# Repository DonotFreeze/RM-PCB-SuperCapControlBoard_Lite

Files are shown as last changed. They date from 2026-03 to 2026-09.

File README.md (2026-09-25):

# 超级电容控制板 Lite

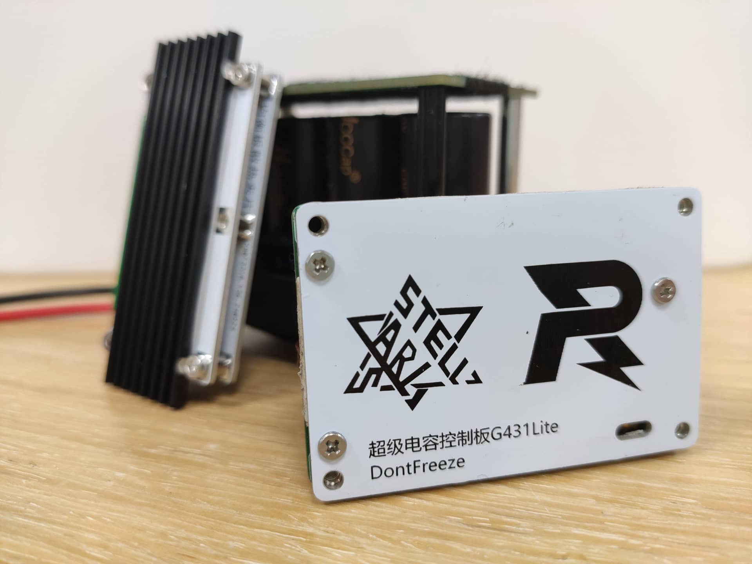
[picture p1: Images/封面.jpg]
超级电容控制板 Lite 封面


> 桂林理工大学 · 群星战队 · RoboMaster 2024 赛季开源工程

基于 **STM32G431CB** 的单半桥双向同步 Buck-Boost 超级电容控制板，用于 RoboMaster 机甲大师赛 2024 赛季高校联盟赛、超级对抗赛以及 2025 赛季高校联盟赛。Lite 版本在**保留上一代半桥功率拓扑**的前提下，对外围芯片重新选型，尽量精简外围电路，希望以较小的成本和体积实现较高的性能，并补充了半桥关键测试点与便于调试的板载资源。

> **完整的硬件设计说明** → [RM2024 超级电容控制板 Lite「硬件篇」 · DonotFreeze 的知识库](https://donotfreeze.github.io/robomaster/supercap-controller-lite-hardware/)

## 主要特性

- **单电感同步半桥**：PMOS 防倒灌 + 半桥 Buck/Boost，与半桥 NMOS 的体二极管方向相反，两者同时截止即可完全断开电容组与母线。
- **100 kHz 开关频率**：STM32G4 的 PWM 抖动模式可将分辨率提升至最高 20 位，100 kHz 下约 27200 个计数值可用（未开启时仅 1700），并使用内部 2.5 V 基准作为 ADC 参考，减小 LDO 精度对采样的影响。
- **完整的采样链路**：母线电流单向高边采样（INA139）、电容组电流双向采样（INA181A2 + 1.65 V 偏置）、母线/电容组电压电阻分压，均经 RC 10 kHz 低通滤波后送入 ADC。
- **温度监控**：半桥附近板载 NTC，电容组温度经 MX1.25 接口外接 NTC，为软件过温保护提供依据。
- **调试友好**：半桥关键测试点、复位/复用按键、拨码开关、两路状态指示灯、SWD 下载口。
- **小体积**：约 60 × 40 mm，配合电容组与裁判系统电源管理模块可塞入装甲板支架之间的位置。

## 硬件规格

| 项目 | 参数 |
| --- | --- |
| 主控 | STM32G431CBT6 |
| 拓扑 | 同步 Buck-Boost 半桥（降压充电 / 升压放电） |
| 开关频率 | 100 kHz（PWM 抖动模式） |
| 半桥 MOS | IRFH7440TRPBF × 2 |
| 防倒灌 PMOS | AGM60P100A |
| 栅极驱动 | EG2181 |
| 电感 | 106-125 磁环 11 匝 ≈ 22 µH（16 A 偏置下约 10.9 µH） |
| 母线电流采样 | 2 mΩ + INA139（单向，量程约 12.5 A） |
| 电容电流采样 | 1 mΩ + INA181A2（双向，+17 A / −33 A） |
| 电压采样 | 电阻分压 + LMV321 跟随器 |
| 温度采样 | 半桥 NTC + 外接电容组 NTC |
| 通信 | CAN |
| 辅助电源 | JW5026 × 2（24 V → 10 V / 4 V）+ RT9193（3.3 V） |
| 保护 | 母线 TVS、电容端口 TVS `SMCJ22A`、辅助电源输入自恢复保险丝 |
| 尺寸 | 约 60 × 40 mm × 1.6 mm |

## 工程结构

```text
├─ SuperCapPowerBoard_Lite.kicad_pro   # KiCad 8.0 工程文件
├─ SuperCapPowerBoard_Lite.kicad_sch   # 主控原理图
├─ SuperCapPowerBoard_Lite.kicad_pcb   # PCB 布局与走线
├─ POWER.kicad_sch                     # 功率级原理图
├─ bom/
│  └─ BOM_LITE_2610.html               # 交互式 BOM（点击可定位元件）
├─ GERBER/
│  └─ GERBER_LITE_2610.zip             # Gerber 与钻孔文件
├─ Images/                             # 文档配图
└─ CHANGELOG.md                        # 版本更新日志
```

## 固件代码

本仓库为**纯硬件工程**，不包含固件源码。固件由以下两个独立仓库提供，与本硬件配套使用：

| 仓库 | 说明 |
| --- | --- |
| [**RM-CODE-SuperCapControlBoard_Lite**](https://github.com/DonotFreeze/RM-CODE-SuperCapControlBoard_Lite) | RM2024 赛季超级电容控制板 Lite 的 **CubeMX 代码初始化工程**，提供 STM32 底层外设的 CubeMX 配置 |
| [**RM-SuperCapCtrlLib**](https://github.com/DonotFreeze/RM-SuperCapCtrlLib) | 参加 RoboMaster 机甲大师赛期间开发的 **C 语言库**，可同时用于超级电容控制板 **Lite 和 Plus**，负责充放电环路控制与对外接口 |

## 物料与打样

- BOM 见 `bom/BOM_LITE_2610.html`，Gerber 生产文件见 `GERBER/GERBER_LITE_2610.zip`，可直接送厂打样。
- **磁环电感需自行采购**：`106-125` 磁环（四线 1.0 mm 并绕 11 匝，初始感量约 22 µH）。
- 电容类元件耐压建议 ≥ 35 V；母线侧元件按电池满电 26 V 以上留足冗余。
- 成本参考 84 RMB/套（2024 年 10 月）。

## 参考资料

设计过程中参考的应用笔记与手册如下，完整的设计思路与参数推导见文首的「硬件篇」：

- 《RM0440 - STM32G4 系列参考手册》（PWM 抖动模式、ADC 相关章节）
- 《AN2834 - 如何在 STM32 微控制器中获得最佳 ADC 精度》
- 《AN5690 - 如何在 STM32 MCU 和 MPU 上使用 VREFBUF 外设》
- 《LAT1076 - STM32G4 Advanced Timer Break 功能详解》
- 《LAT1444 - ADC 采样中的阻抗匹配计算方法》
- 《MOSFET 驱动器与 MOSFET 的匹配设计》
- 《低压非隔离 DCDC 开关稳压器设计》
- 《精密低噪声电源设计 - 理论篇》
- 《热回路究竟是什么？》
- 《如何通过最小化热回路 PCB ESR 和 ESL 来优化开关电源布局》
- 《改进低值分流电阻的焊盘布局，优化高电流检测精度》

## 许可证

本作品采用 [CC-BY-4.0](LICENSE) 许可协议进行授权，欢迎转载，但请务必保留作者署名。

## 相关链接

- [RM2024 超级电容控制板 Lite「硬件篇」](https://donotfreeze.github.io/robomaster/supercap-controller-lite-hardware/)（本工程的设计说明）
- [固件代码 · RM-CODE-SuperCapControlBoard_Lite](https://github.com/DonotFreeze/RM-CODE-SuperCapControlBoard_Lite)（CubeMX 代码初始化工程）
- [固件代码 · RM-SuperCapCtrlLib](https://github.com/DonotFreeze/RM-SuperCapCtrlLib)（Lite / Plus 通用的 C 语言库）
- [RM2025 超级电容控制板 Plus「硬件篇」](https://donotfreeze.github.io/robomaster/supercap-controller-plus-hardware/)
- [RM2024 超级电容模组 Lite「使用手册」](https://donotfreeze.github.io/robomaster/supercap-module-lite-user-manual/)
- [RM24-25 超级电容控制板 Lite & Plus「CubeMX 篇」](https://donotfreeze.github.io/robomaster/supercap-controller-cubemx/)
- [RM24-25 超级电容控制板 Lite & Plus「软件篇」](https://donotfreeze.github.io/robomaster/supercap-controller-software/)
- [RM24-25 超级电容模组 Lite & Plus「维护手册」](https://donotfreeze.github.io/robomaster/supercap-module-maintenance-manual/)
- [RM24-25 超级电容模组 Lite & Plus「答疑篇」](https://donotfreeze.github.io/robomaster/supercap-module-faq/)
- [DonotFreeze 的知识库](https://donotfreeze.github.io/)

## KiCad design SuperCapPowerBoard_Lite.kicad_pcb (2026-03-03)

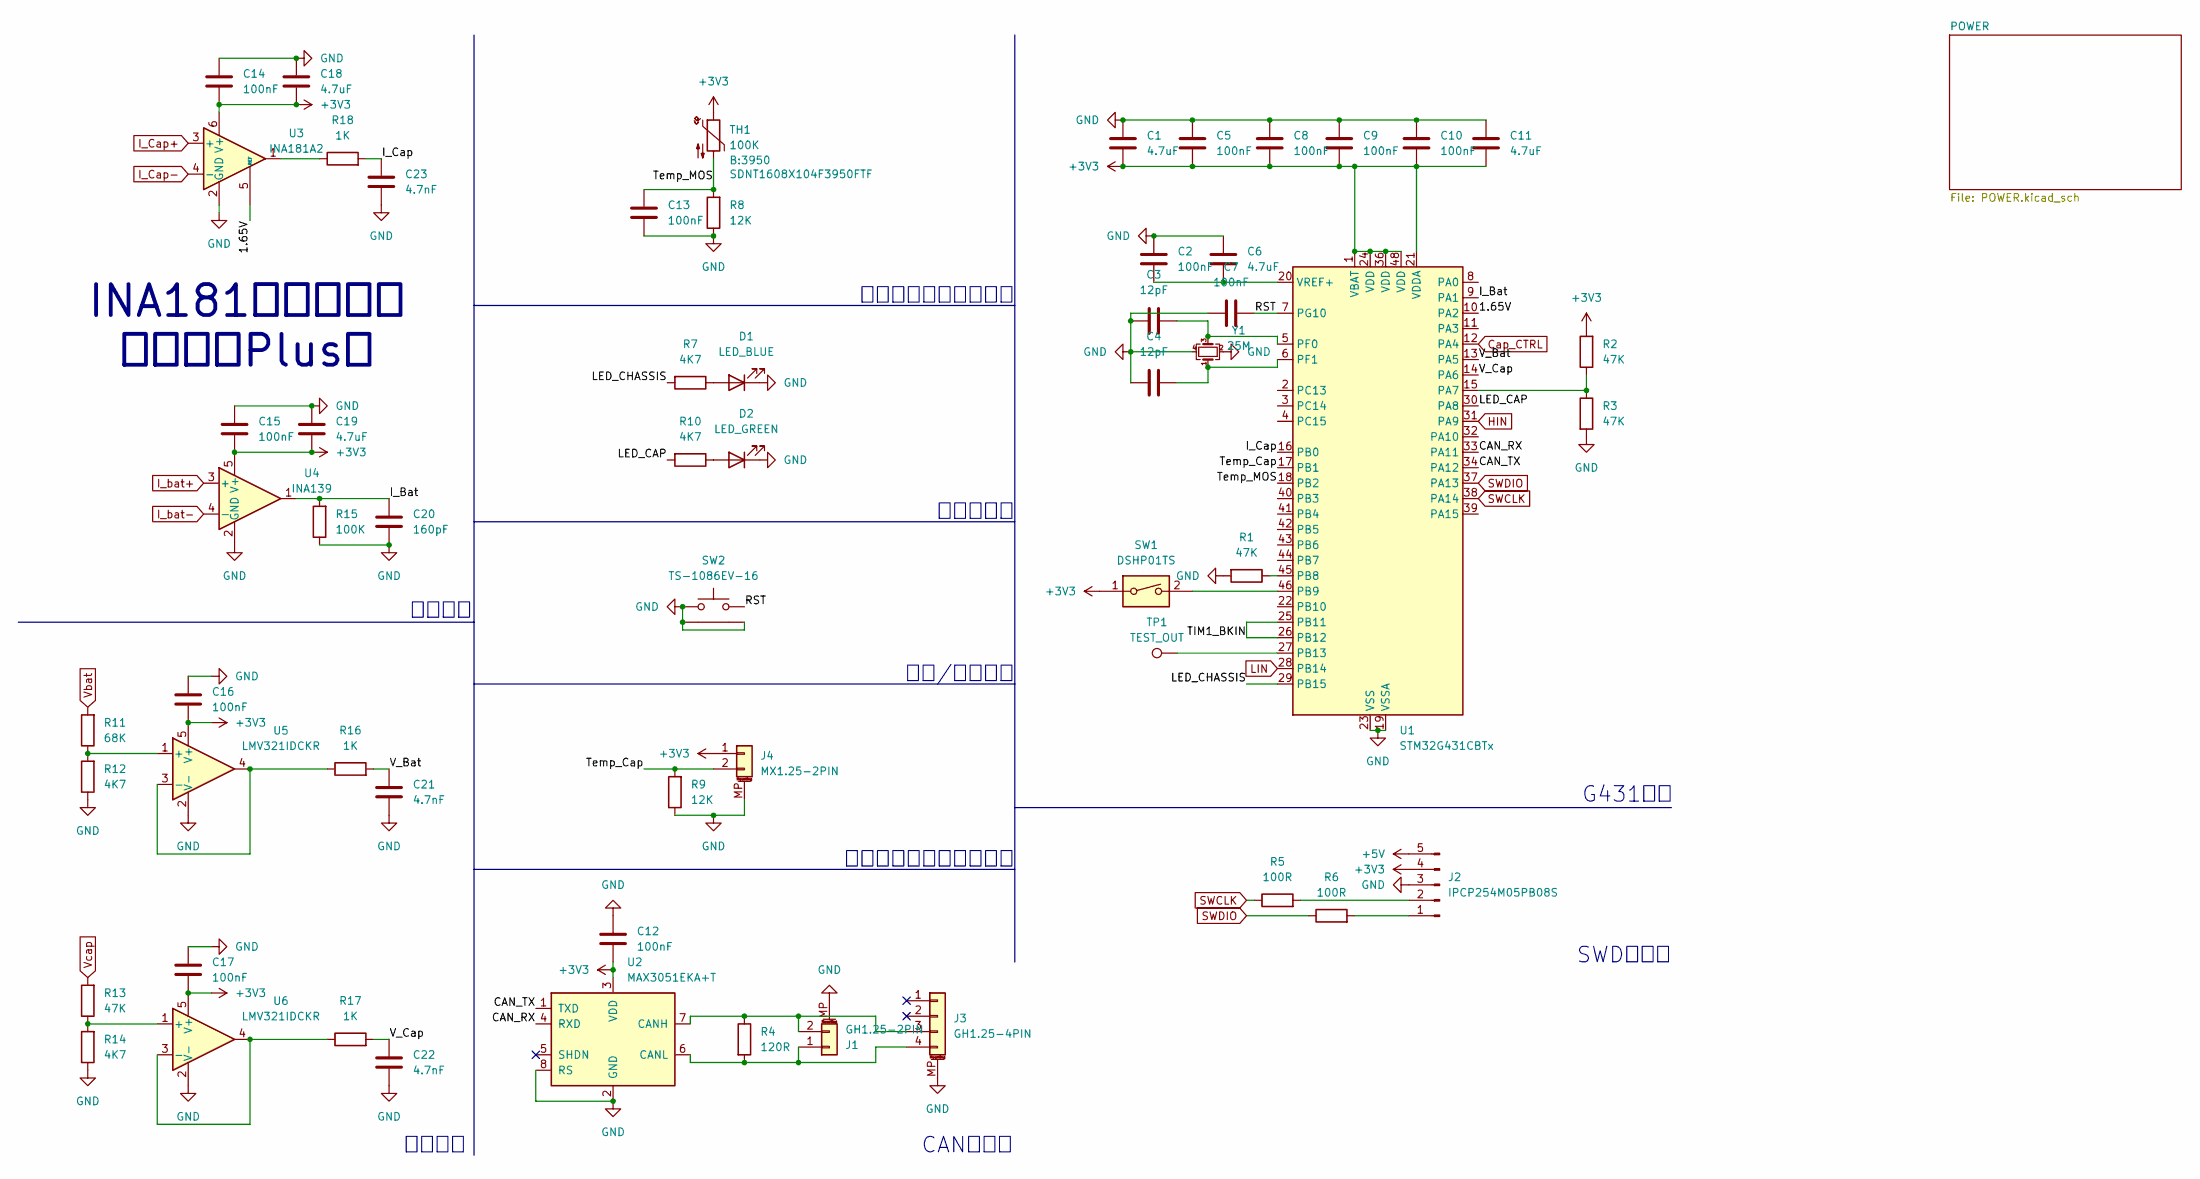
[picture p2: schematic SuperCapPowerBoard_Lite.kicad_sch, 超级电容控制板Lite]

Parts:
C1, C6, C11, C18, C19: 4.7uF; C_0603_1608Metric
C2, C5, C7, C8, C9, C10, C12, C13, C14, C15, C16, C17: 100nF; C_0603_1608Metric
C3, C4: 12pF; C_0603_1608Metric
C20: 160pF; C_0603_1608Metric
C21, C22, C23: 4.7nF; C_0603_1608Metric
D1: LED_BLUE; LED_0805_2012Metric
D2: LED_GREEN; LED_0805_2012Metric
J1: GH1.25-2PIN; JST_GH_BM02B-GHS-TBT_1x02-1MP_P1.25mm_Vertical
J2: IPCP254M05PB08S; PinHeader_1x05_P2.54mm_Vertical_SMD_Pin1Left
J3: GH1.25-4PIN; JST_GH_BM04B-GHS-TBT_1x04-1MP_P1.25mm_Vertical
J4: MX1.25-2PIN; Molex_PicoBlade_53398-0271_1x02-1MP_P1.25mm_Vertical
R1, R2, R3, R13: 47K; R_0603_1608Metric
R4: 120R; R_0603_1608Metric
R5, R6: 100R; R_0603_1608Metric
R7, R10, R12, R14: 4K7; R_0603_1608Metric
R8, R9: 12K; R_0603_1608Metric
R11: 68K; R_0603_1608Metric
R15: 100K; R_0603_1608Metric
R16, R17, R18: 1K; R_0603_1608Metric
SW1: DSHP01TS; SW_DIP_SPSTx01_Slide_Copal_CHS-01B_W7.62mm_P1.27mm
SW2: TS-1086EV-16; SW_Push_1P1T-MP_NO_TS-1086EV-AR03526
TH1: 100K; R_0603_1608Metric
TP1: TEST_OUT; TestPoint_Pad_D1.5mm
U1: STM32G431CBTx; LQFP-48_7x7mm_P0.5mm
U2: MAX3051EKA+T; SOT-23-8
U3: INA181A2; SOT-23-6
U4: INA139; SOT-23-5
U5, U6: LMV321IDCKR; SOT-353_SC-70-5
Y1: 25M; Crystal_SMD_2016-4Pin_2.0x1.6mm

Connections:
+3V3: C1.2, C5.2, C8.2, C9.2, C10.2, C11.2, C12.2, C14.1, C15.1, C16.1, C17.1, C18.1, C19.1, J2.4, J4.1, R2.2, SW1.1, TH1.1, U1.1 (VBAT), U1.21 (VDDA), U1.24 (VDD), U1.36 (VDD), U1.48 (VDD), U2.3 (VDD), U3.6 (V+), U4.5 (V+), U5.5 (V+), U6.5 (V+); also elsewhere on the board
+5V: J2.5; also elsewhere on the board
/1.65V: U1.10 (PA2), U3.5 (REF)
/CAN_RX: U1.33 (PA11), U2.4 (RXD)
/CAN_TX: U1.34 (PA12), U2.1 (TXD)
/I_Bat: C20.2, R15.2, U1.9 (PA1), U4.1
/I_Cap: C23.2, R18.2, U1.16 (PB0)
/LED_CAP: R10.2, U1.30 (PA8)
/LED_CHASSIS: R7.2, U1.29 (PB15)
/RST: C7.2, SW2.2, U1.7 (PG10)
/TIM1_BKIN: U1.25 (PB11), U1.26 (PB12)
/Temp_Cap: J4.2, R9.2, U1.17 (PB1)
/Temp_MOS: C13.1, R8.2, TH1.2, U1.18 (PB2)
/V_Bat: C21.2, R16.2, U1.13 (PA5)
/V_Cap: C22.2, R17.2, U1.14 (PA6)
Cap_CTRL: U1.12 (PA4); also elsewhere on the board
GND: C1.1, C2.1, C3.2, C4.2, C5.1, C6.1, C7.1, C8.1, C9.1, C10.1, C11.1, C12.1, C13.2, C14.2, C15.2, C16.2, C17.2, C18.2, C19.2, C20.1, C21.1, C22.1, C23.1, D1.1 (K), D2.1 (K), J1.MP (MountPin), J2.3, J3.MP (MountPin), J4.MP (MountPin), R1.2, R3.2, R8.1, R9.1, R12.1, R14.1, R15.1, SW2.1, SW2.MP, U1.19 (VSSA), U1.23 (VSS), U1.35 (VSS), U1.47 (VSS), U2.2 (GND), U2.8 (RS), U3.2 (GND), U4.2 (GND), U5.2 (V-), U6.2 (V-), Y1.2, Y1.4; also elsewhere on the board
HIN: U1.31 (PA9); also elsewhere on the board
I_Cap+: U3.3 (+); also elsewhere on the board
I_Cap-: U3.4 (-); also elsewhere on the board
I_bat+: U4.3 (+); also elsewhere on the board
I_bat-: U4.4 (-); also elsewhere on the board
LIN: U1.28 (PB14); also elsewhere on the board
unnamed: D1.2 (A), R7.1
unnamed: D2.2 (A), R10.1
unnamed: J1.1, J3.4, R4.2, U2.6 (CANL)
unnamed: J1.2, J3.3, R4.1, U2.7 (CANH)
unnamed: J2.1, R6.2
unnamed: J2.2, R5.2
unnamed: R18.1, U3.1
unnamed: R2.1, R3.1, U1.15 (PA7)
unnamed: R1.1, U1.45 (PB8)
unnamed: SW1.2, U1.46 (PB9)
unnamed: TP1.1, U1.27 (PB13)
unnamed: C3.1, U1.5 (PF0), Y1.3
unnamed: C4.1, U1.6 (PF1), Y1.1
unnamed: C2.2, C6.2, U1.20 (VREF+)
unnamed: R11.1, R12.2, U5.1 (+)
unnamed: R16.1, U5.3 (-), U5.4
unnamed: R13.1, R14.2, U6.1 (+)
unnamed: R17.1, U6.3 (-), U6.4
SWCLK: R5.1, U1.38 (PA14)
SWDIO: R6.1, U1.37 (PA13)
Vbat: R11.2; also elsewhere on the board
Vcap: R13.2; also elsewhere on the board

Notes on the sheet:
CAN收发器
INA181有烧毁风险 建议使用Plus版
半桥温度检测热敏电阻
电压检测
G431主控
SWD下载口
电流检测
复位/复用按键
状态指示灯
电容组温度检测热敏电阻

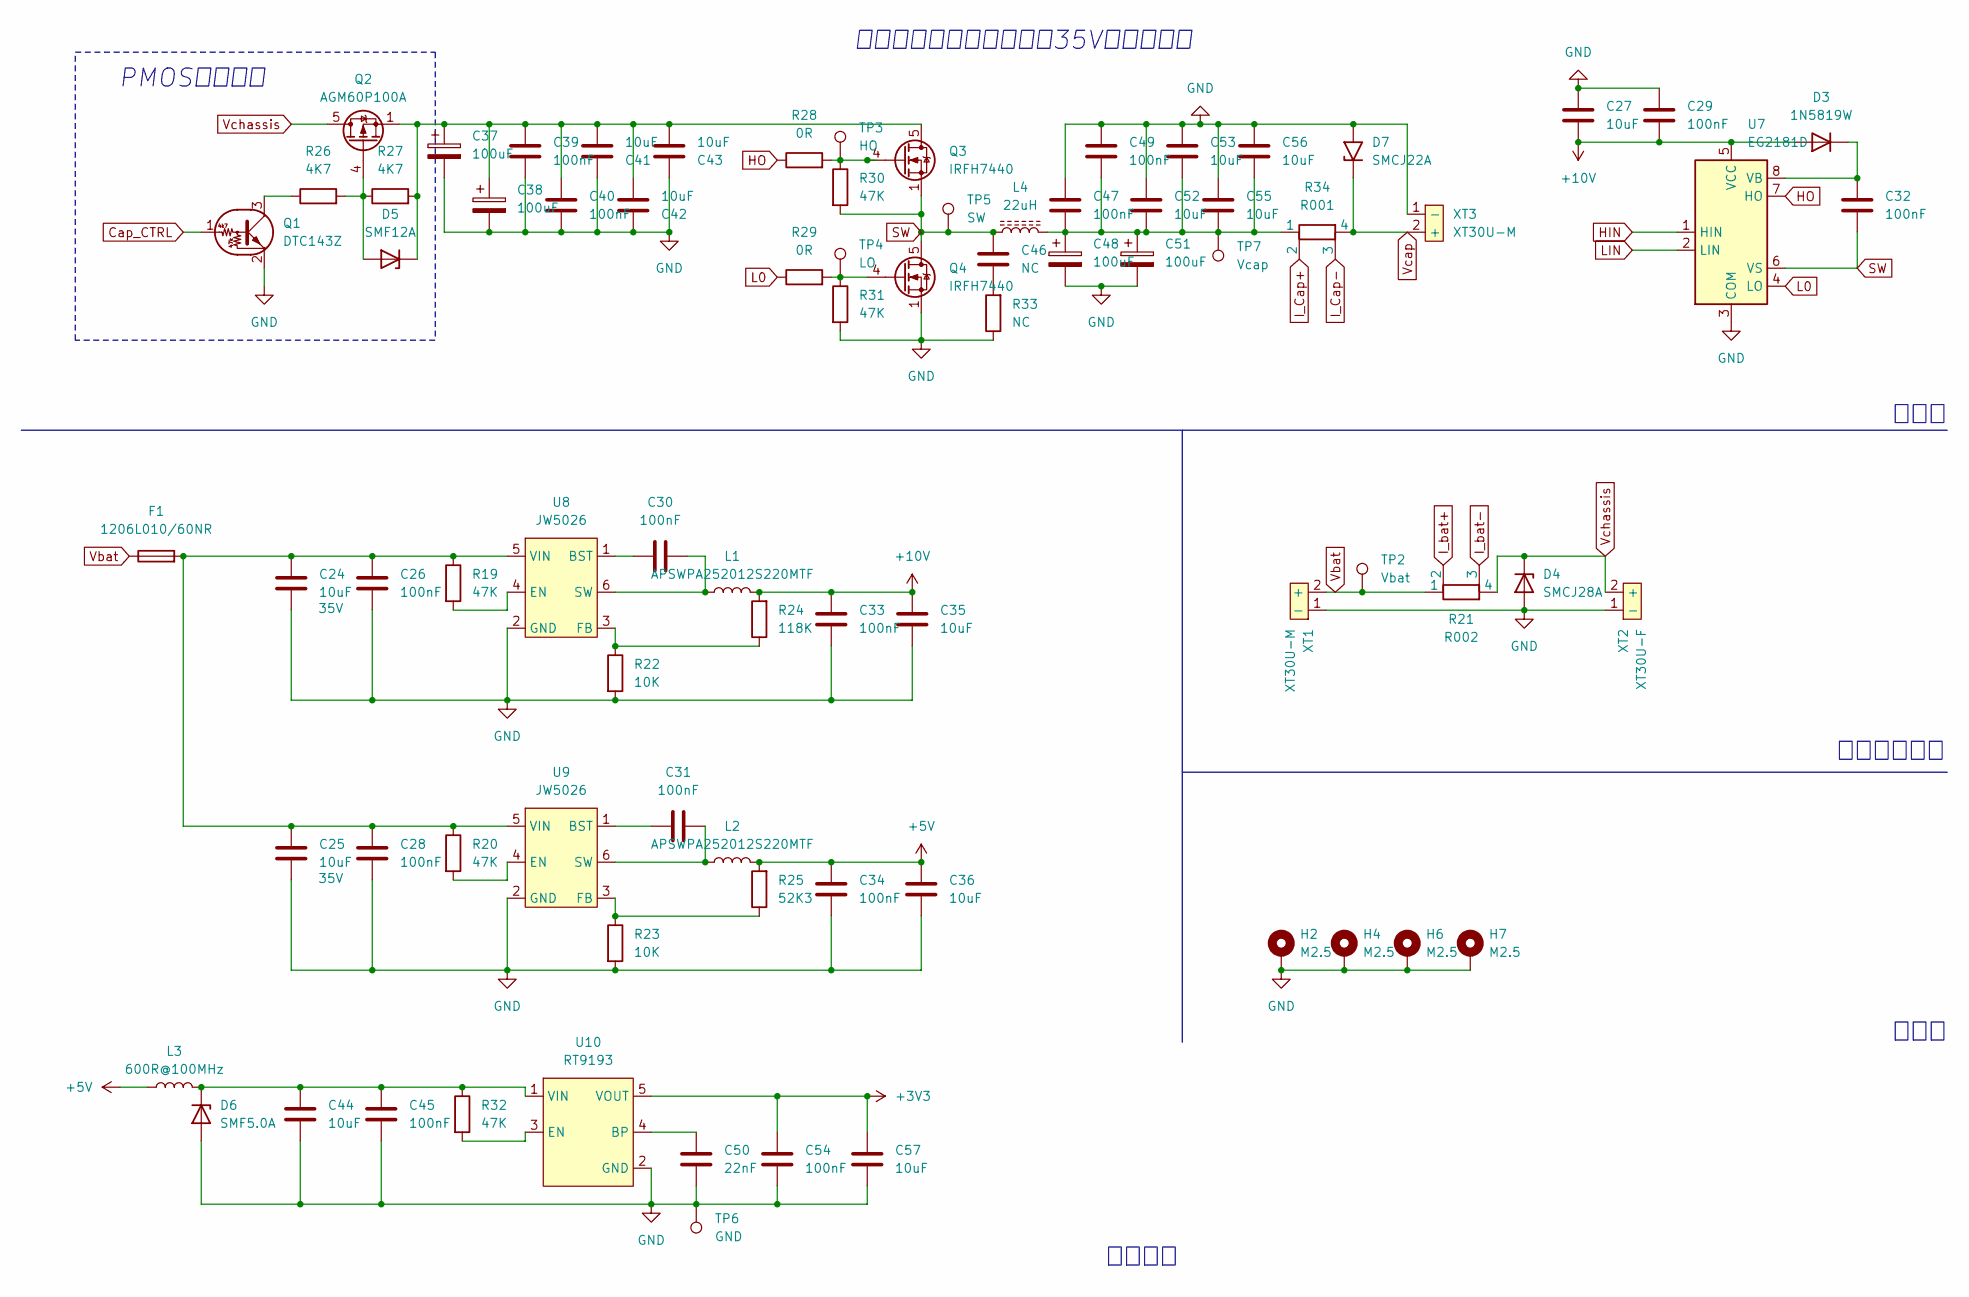
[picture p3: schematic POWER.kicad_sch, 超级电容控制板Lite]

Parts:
C24, C25, C41, C42, C43, C52, C53, C55, C56: 10uF; C_1206_3216Metric
C26, C28, C29, C30, C31, C32, C33, C34, C39, C40, C45, C47, C49, C54: 100nF; C_0603_1608Metric
C27, C35, C36, C44, C57: 10uF; C_0603_1608Metric
C37, C38, C48, C51: 100uF; CP_Radial_D8.0mm_P3.50mm
C46: NC; C_0603_1608Metric
C50: 22nF; C_0603_1608Metric
D3: 1N5819W; D_SOD-123F
D4: SMCJ28A; D_SMC
D5: SMF12A; D_SOD-123F
D6: SMF5.0A; D_SOD-123F
D7: SMCJ22A; D_SMC
F1: 1206L010/60NR; Fuse_1206_3216Metric
H2, H4, H6, H7: M2.5; MountingHole_3.1mm_M2.5
L1, L2: APSWPA252012S220MTF; L_Sunlord_SWPA252012S
L3: 600R@100MHz; L_0805_2012Metric
L4: 22uH; L_106125
Q1: DTC143Z; SOT-23
Q2: AGM60P100A; AO_DFN-8-1EP_5.55x5.2mm_P1.27mm_EP4.12x4.6mm
Q3, Q4: IRFH7440; TDSON-8-1
R19, R20, R30, R31, R32: 47K; R_0603_1608Metric
R21: R002; R_Shunt_2512_6332Metric
R22, R23: 10K; R_0603_1608Metric
R24: 118K; R_0603_1608Metric
R25: 52K3; R_0603_1608Metric
R26, R27: 4K7; R_0603_1608Metric
R28, R29: 0R; R_0603_1608Metric
R33: NC; R_0603_1608Metric
R34: R001; R_Shunt_2512_6332Metric
TP2: Vbat; TestPoint_Pad_D1.5mm
TP3: HO; TestPoint_Pad_D1.5mm
TP4: LO; TestPoint_Pad_D1.5mm
TP5: SW; TestPoint_Pad_D1.5mm
TP6: GND; TestPoint_Pad_D1.5mm
TP7: Vcap; TestPoint_Pad_D1.5mm
U7: EG2181D; SOP-8_3.9x4.9mm_P1.27mm
U8, U9: JW5026; SOT-23-6
U10: RT9193; SOT-23-5
XT1, XT3: XT30U-M; AMASS_XT30U-M_1x02_P5.0mm_Vertical
XT2: XT30U-F; AMASS_XT30U-F_1x02_P5.0mm_Vertical

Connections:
+3V3: C54.1, C57.1, U10.5 (VOUT); also elsewhere on the board
+5V: C34.1, C36.1, L2.2, L3.1, R25.2; also elsewhere on the board
+10V: C27.2, C29.1, C33.1, C35.1, D3.2 (A), L1.2, R24.2, U7.5 (VCC)
Cap_CTRL: Q1.1 (B); also elsewhere on the board
GND: C24.2, C25.2, C26.2, C27.1, C28.2, C29.2, C33.2, C34.2, C35.2, C36.2, C37.2, C38.2, C39.1, C40.1, C41.1, C42.1, C43.1, C44.2, C45.2, C47.2, C48.2, C49.2, C50.2, C51.2, C52.1, C53.1, C54.2, C55.1, C56.1, C57.2, D4.2 (A), D6.2 (A), D7.2 (A2), H2.1, H4.1, H6.1, H7.1, Q1.2 (E), Q4.1 (S), Q4.2 (S), Q4.3 (S), R22.2, R23.2, R31.2, R33.1, TP6.1, U7.3 (COM), U8.2 (GND), U9.2 (GND), U10.2 (GND), XT1.1 (-), XT2.1 (-), XT3.1 (-); also elsewhere on the board
HIN: U7.1 (HIN); also elsewhere on the board
HO: R28.1, U7.7 (HO)
I_Cap+: R34.2; also elsewhere on the board
I_Cap-: R34.3; also elsewhere on the board
I_bat+: R21.2; also elsewhere on the board
I_bat-: R21.3; also elsewhere on the board
L0: R29.1, U7.4 (LO)
LIN: U7.2 (LIN); also elsewhere on the board
unnamed: C46.1, R33.2
unnamed: C47.1, C48.1, C49.1, C51.1, C52.2, C53.2, C55.2, C56.2, L4.1, R34.1, TP7.1
unnamed: C32.1, D3.1 (K), U7.8 (VB)
unnamed: D5.2 (A), Q2.4 (G), R26.2, R27.1
unnamed: C37.1, C38.1, C39.2, C40.2, C41.2, C42.2, C43.2, D5.1 (K), Q2.1 (S), Q2.2 (S), Q2.3 (S), Q3.5 (D), R27.2
unnamed: C44.1, C45.1, D6.1 (K), L3.2, R32.1, U10.1 (VIN)
unnamed: Q1.3 (C), R26.1
unnamed: Q3.4 (G), R28.2, R30.1, TP3.1
unnamed: Q4.4 (G), R29.2, R31.1, TP4.1
unnamed: C30.1, U8.1 (BST)
unnamed: R19.2, U8.4 (EN)
unnamed: R22.1, R24.1, U8.3 (FB)
unnamed: C30.2, L1.1, U8.6 (SW)
unnamed: C24.1, C25.1, C26.1, C28.1, F1.2, R19.1, R20.1, U8.5 (VIN), U9.5 (VIN)
unnamed: C31.1, U9.1 (BST)
unnamed: R20.2, U9.4 (EN)
unnamed: R23.1, R25.1, U9.3 (FB)
unnamed: C31.2, L2.1, U9.6 (SW)
unnamed: C50.1, U10.4 (BP)
unnamed: R32.2, U10.3 (EN)
SW: C32.2, C46.2, L4.2, Q3.1 (S), Q3.2 (S), Q3.3 (S), Q4.5 (D), R30.2, TP5.1, U7.6 (VS)
Vbat: F1.1, R21.1, TP2.1, XT1.2 (+); also elsewhere on the board
Vcap: D7.1 (A1), R34.4, XT3.2 (+); also elsewhere on the board
Vchassis: D4.1 (K), Q2.5 (D), R21.4, XT2.2 (+)

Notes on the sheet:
机械孔
PMOS关断电路
这里的电容全部使用耐压35V或者以上的
主拓扑
底盘并联支路
辅助电源

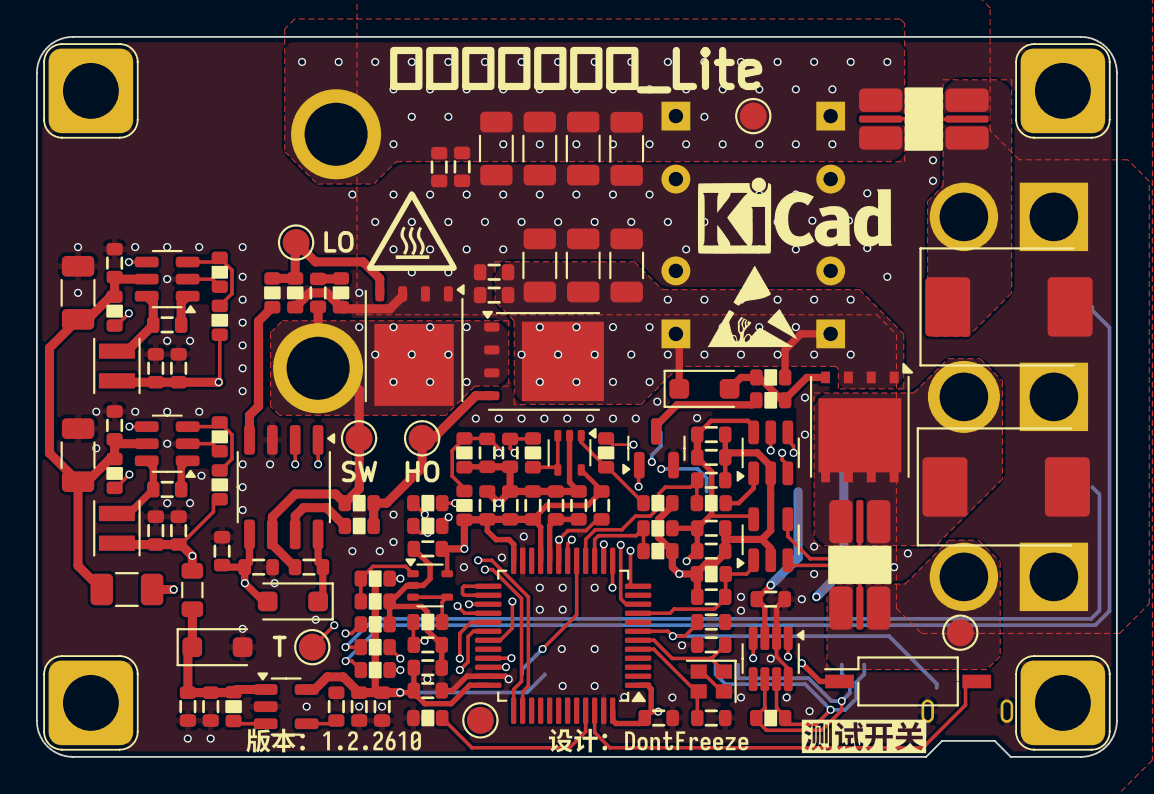
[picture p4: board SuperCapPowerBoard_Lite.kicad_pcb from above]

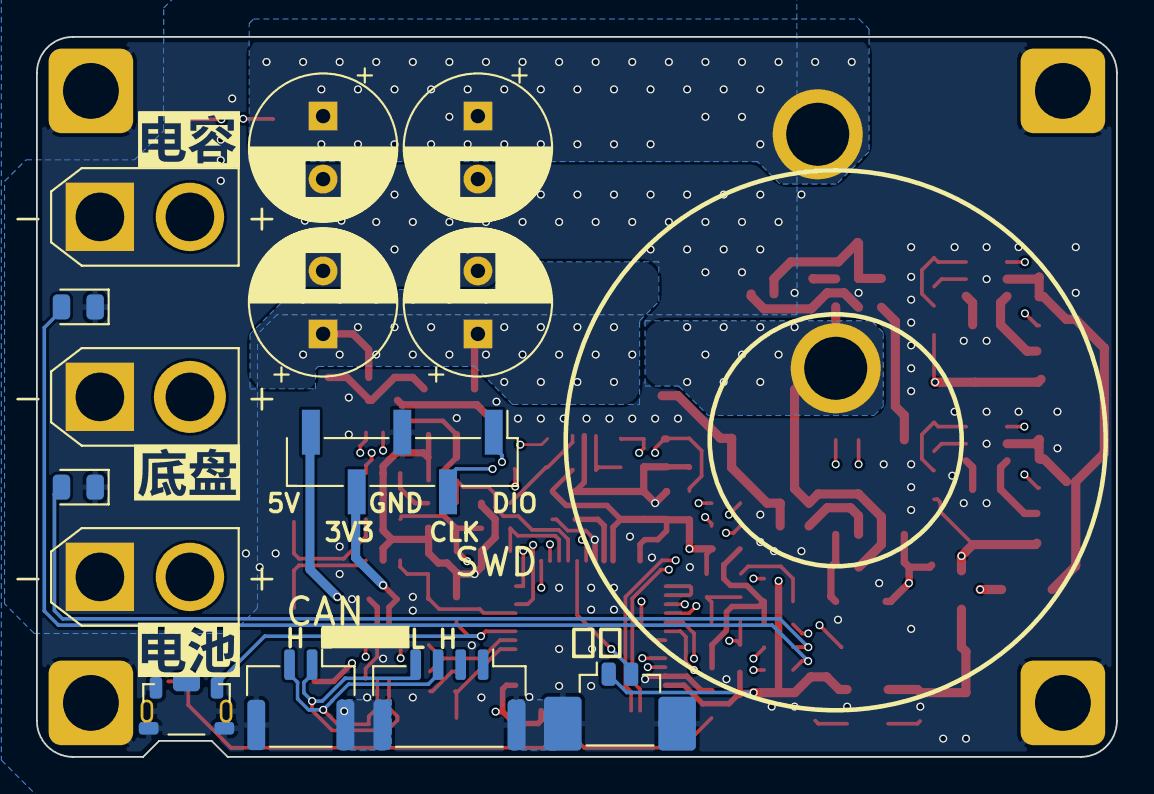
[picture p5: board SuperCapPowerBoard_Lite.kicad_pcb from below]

Board: 4 copper layers, 60.0 x 40.0 mm, 139 parts (15 on the bottom side), 70 nets.

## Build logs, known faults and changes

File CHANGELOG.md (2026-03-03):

# 更新日志

## [1.2.2610] - 2026-03-03

### 新增

- 电容端口新增SMCJ22A
- 辅助电源输入增加自恢复保险丝

### 变更

- 删除无用的固定孔
- 更改测试点封装
- 修改辅助电源的分压电阻使其与Plus相同

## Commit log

2026-03-03 上传2610版本
    [POWER.kicad_sch, SuperCapPowerBoard_Lite.kicad_pcb, SuperCapPowerBoard_Lite.kicad_sch]
2026-03-03 添加LICENSE文件
2026-03-04 docs(README): 添加超级电容控制板Lite项目详细文档
2026-03-05 ``` feat(.gitignore): 添加.lck文件到忽略列表
    feat(/docs): 添加参考文件PDF
    fix(README): 更新MOS管型号和相关技术参数
    change(/Images): 将所有图片进行压缩
    ```
2026-09-25 docs(readme): 精简并重构项目说明文档
